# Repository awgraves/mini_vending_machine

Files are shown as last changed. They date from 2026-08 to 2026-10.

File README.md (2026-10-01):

# mini_vending_machine
A desktop-sized machine that dispenses snacks via a 2-axis motorized gantry

## Local Dev Setup
Assumes a Linux host

### Requirements
[Devenv.sh](https://devenv.sh/getting-started/) is the only direct dependency.
It is a convenient way to create deterministic, reproducible dev environments with automatic tooling setup!
Devenv uses the nix package manager and will automatically download and install isolated tooling dependencies that will not pollute your host system.
See the 'steps' section below.

#### Permissions
Assuming you are on linux:
For dfu-util (openocd flashing) & picocom (serial monitor) access, there are 2 options:
1. Use sudo for `sudo make flash` and `sudo make monitor`
2a. Add udev rule:
```
  SUBSYSTEM=="tty", ATTR{idVendor}=="0483", MODE="0666", TAG+="uaccess"
```
2b. Add 'dialout' group for your user for picocom (requires complete logout to take effect).

### Steps
1. Before cloning the repo, first create a workspace dir ie `mkdir workspace`
2. `cd` into the newly created dir and git clone this repo there.
3. Ensure nix package manager and devenv is installed, then exec `devenv shell` to enter the development shell.
All software dependencies will be automatically installed to a sandboxed environment!
The first time setup will take some time, but subsequent dev shell loads will be super quick.
You can leave the shell with `exit`.

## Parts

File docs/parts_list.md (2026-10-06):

# Parts List

## Frame
- [400mm vslot 2020](https://www.amazon.com/dp/B099MRRKJ2) x 6 pieces
- [400mm vslot 2040](https://www.amazon.com/dp/B0BZ57L6CB) x 4 pieces
- [450mm vslot 2020](https://www.amazon.com/dp/B099MJN26Z) x 4 pieces
- [L corner brackets](https://www.amazon.com/dp/B0F31DXF4F) x 12 pieces

## 3D Printer Filaments
- [Black PETG](https://www.amazon.com/dp/B07PGYHYV8)
- [White PLA+](https://www.amazon.com/dp/B09Q5YJ5HZ)

## PCB Boards, Wires, Connectors
- [9x15cm double sided prototype circuit boards](https://www.amazon.com/dp/B08WJBS4HK) x 2 pieces
- [22 awg stranded wire](https://www.amazon.com/dp/B07G2JWYDW)
- [22 awg solid core wire](https://www.amazon.com/dp/B07TX6BX47)
- TODO, jst connector info

## Gantry
- [STM32 blackpill F411CE](https://www.amazon.com/dp/B0DLNDY4V7) x 1 piece
- [nema 17 pancake stepper motors](https://www.amazon.com/dp/B088BNVTBF) x 2 pieces
- [limit switches](https://www.amazon.com/dp/B09K7K3486) x 2 pieces
- 100nF ceramic capacitors for switch debouncing x 2 pieces
- 10k ohm pullup resistors for switches x 2 pieces
- [TMC2209 stepper motor drivers](https://www.amazon.com/dp/B08WZFK9KT) x 2 pieces
- [100uF 50V electrolytic capacitors](https://www.amazon.com/dp/B0FVG9S7N6) for motor driver decoupling x 2 pieces

### X Axis
- [350mm vslot 2040](https://www.amazon.com/dp/B08X4NFVT6) (400mm cut down to 350mm)
- [350mm MGN9 linear rail](https://www.amazon.com/dp/B094CYT6JW) x 1 piece
- [GT2 6mm wide timing belt kit](https://www.amazon.com/dp/B07TGGVSTP)  x 1 piece
- M3 x 8mm screws & T nuts x 16 pieces for rail attachment
- [Nema 17 mount plate](https://www.amazon.com/dp/B07V3Q4WFL) x 1 piece

### Y Axis
- [300mm T8 leadscrew](https://www.amazon.com/dp/B0981YZ7DN) x 1 piece
- [Backlash-resistant T8 leadscrew nut](https://www.amazon.com/dp/B0B2P9KBH8) x 1 piece
- M5 x 16mm & hex nuts x 2 pieces to connect leadscrew nut to carriage wedge
- [5mm to 8mm flexible coupling for Nema 17](https://www.amazon.com/dp/B079J22KX1) x 1 piece
- Bearing (came with [this kit](https://www.amazon.com/dp/B08T9PL29W)) x 1 piece
- [400mm MGN9 linear rail](https://www.amazon.com/dp/B094CXXPLG)
- M3 x 8mm screws & T nuts x 18 pieces for rail attachment

## Dispenser
- M3 x 6mm screws & hex nuts x 16 pieces for inter-cubby attachments
- M3 x 8mm screws & hex nuts x 12 pieces for drawer slide verticle attachments
- [8inch drawer slides](https://www.amazon.com/dp/B0D62TB3V7) x 6 pieces
- M5 x 12mm screws & hex nuts x 12 pieces for drawer slide to cubby attachment
- M5 x 8mm screws & hex nuts x 10 pieces for cubby legs attachments

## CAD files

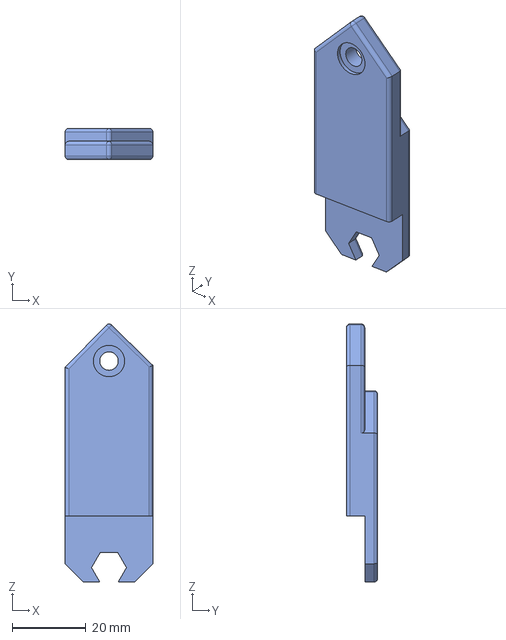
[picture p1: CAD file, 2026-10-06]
docs/3d/cubby_legs_slide_attach.step
23.8 x 8.50 x 69.9 mm

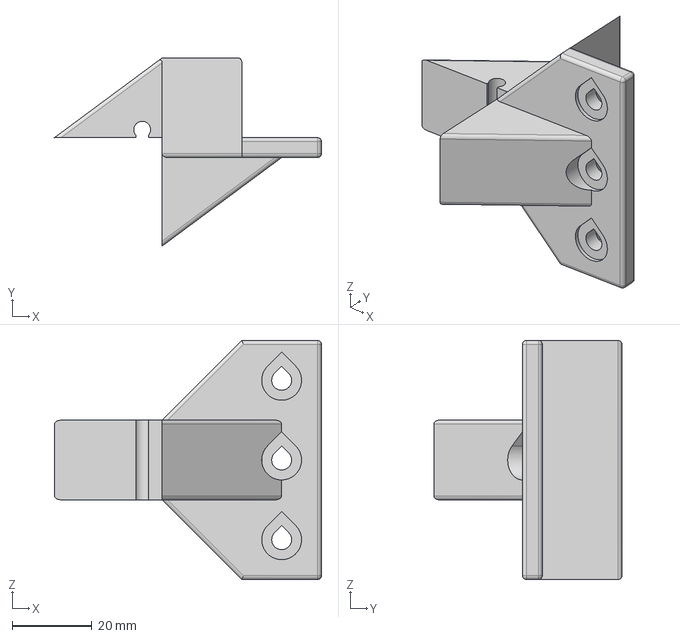
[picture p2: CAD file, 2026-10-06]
docs/3d/cubby_vslot_attachment.step
67.0 x 47.2 x 60.0 mm

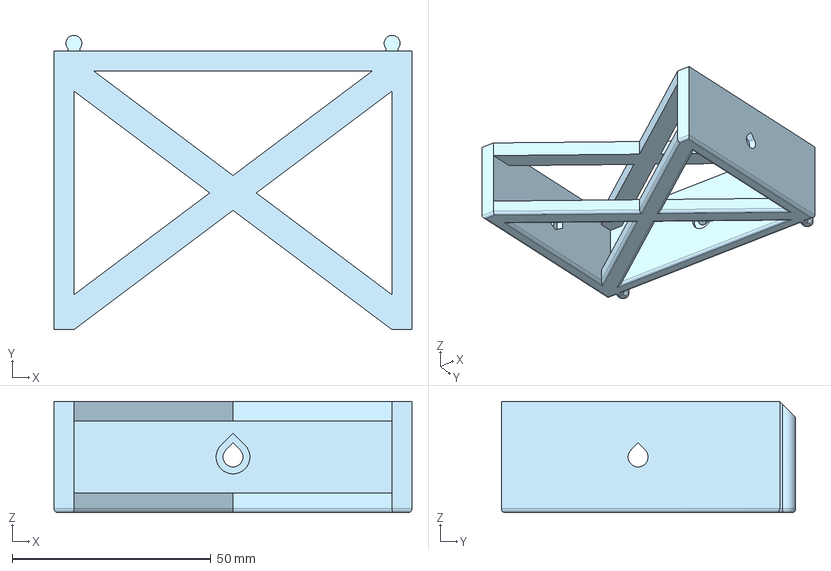
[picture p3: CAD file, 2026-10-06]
docs/3d/cubby_legs.step
90.0 x 74.0 x 28.0 mm

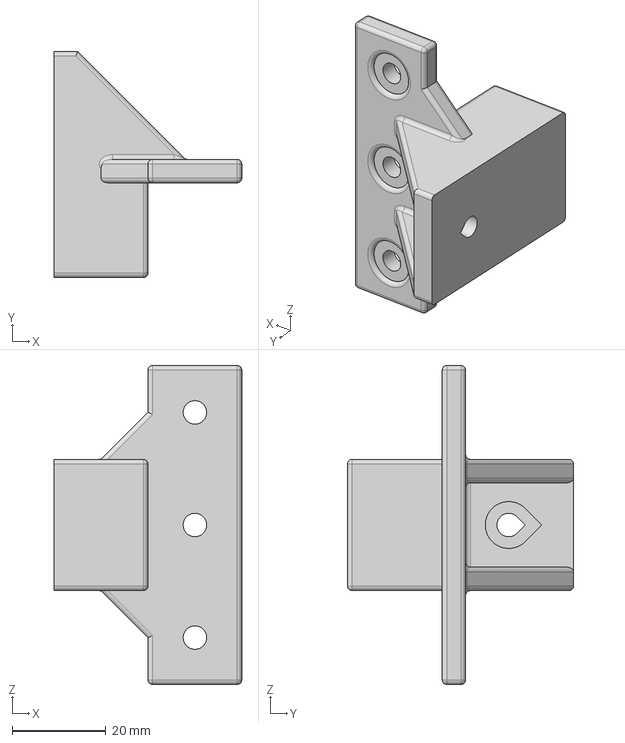
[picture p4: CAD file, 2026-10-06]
docs/3d/cubby_legs_spacer.step
40.0 x 48.2 x 68.0 mm

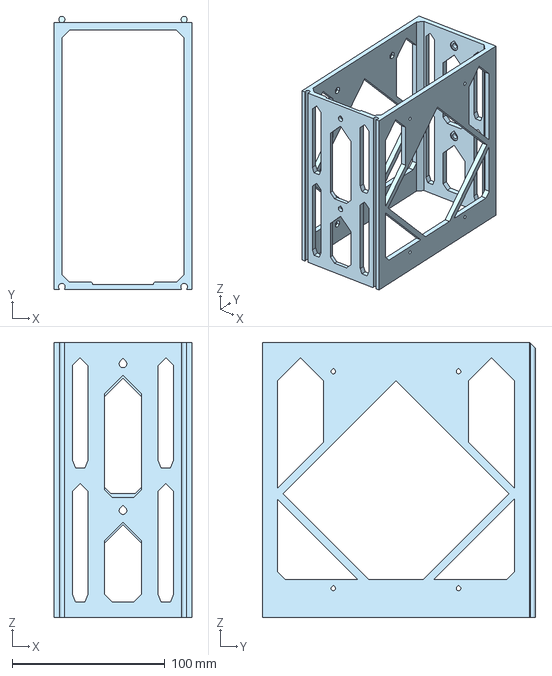
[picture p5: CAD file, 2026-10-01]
docs/3d/cubby_unit.step
90.0 x 179.0 x 180.0 mm

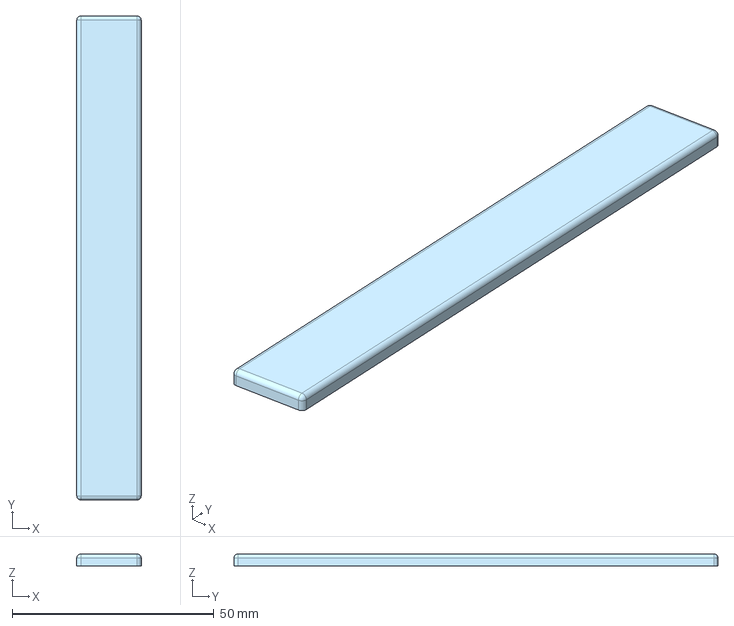
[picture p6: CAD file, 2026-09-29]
docs/3d/120mm_spacer.step
16.0 x 120.0 x 3.00 mm

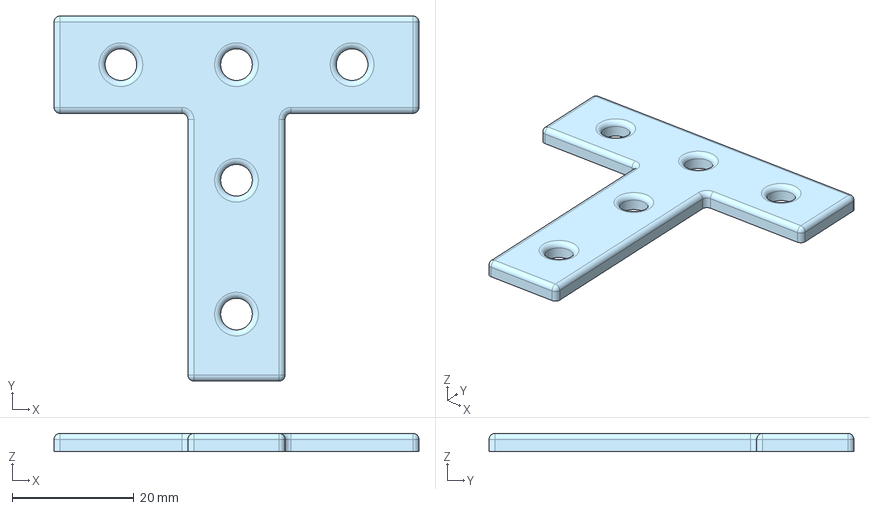
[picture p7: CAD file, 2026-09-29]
docs/3d/t_bracket.step
60.0 x 60.0 x 3.00 mm

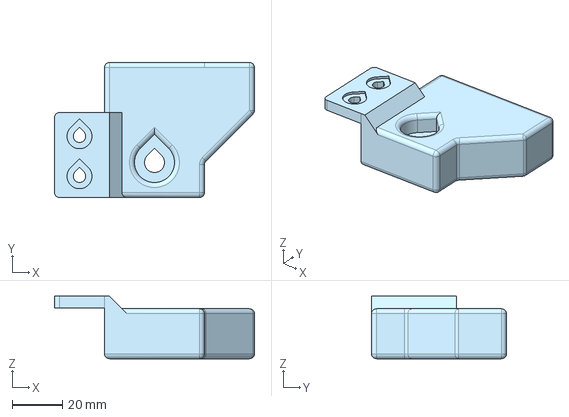
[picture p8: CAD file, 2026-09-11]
docs/3d/y_axis_bearing_bracket.step
80.0 x 54.0 x 25.0 mm

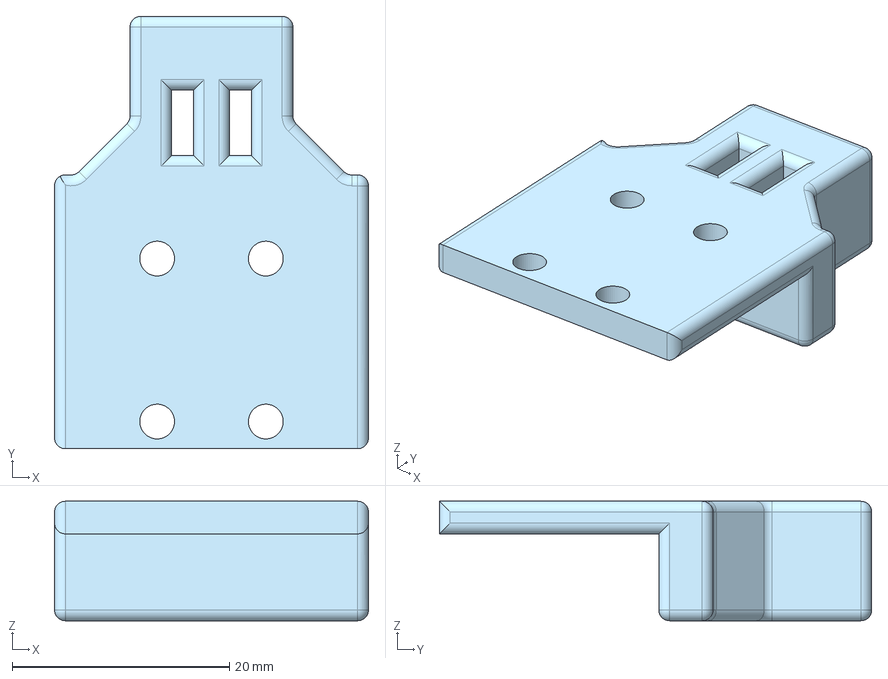
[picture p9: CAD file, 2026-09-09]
docs/3d/x_axis_timing_belt_carriage.step
28.9 x 39.8 x 11.0 mm

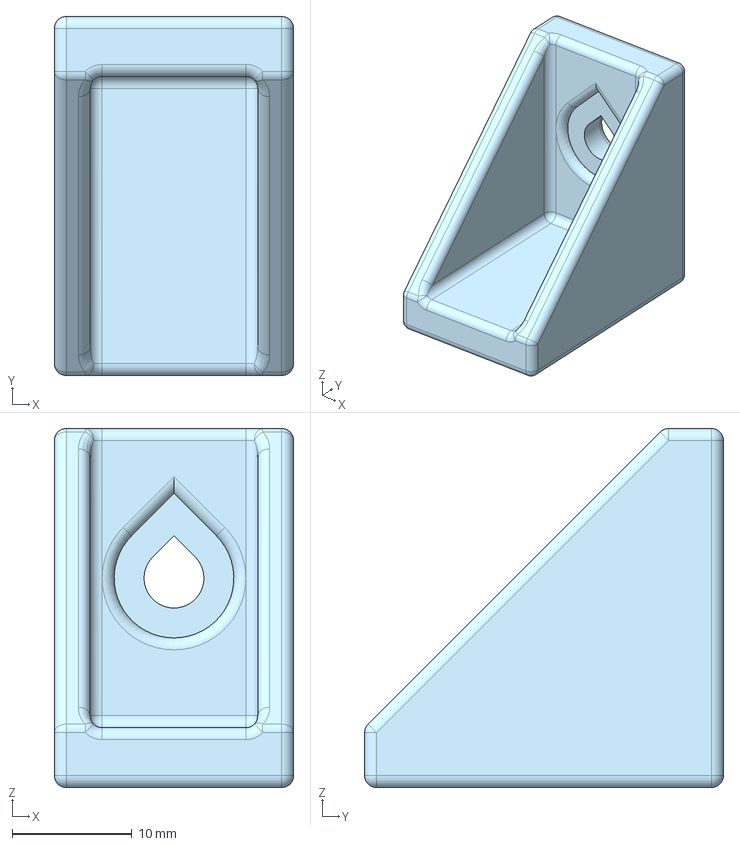
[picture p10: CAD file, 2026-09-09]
docs/3d/y_axis_rail_spacer.step
20.0 x 30.0 x 30.0 mm

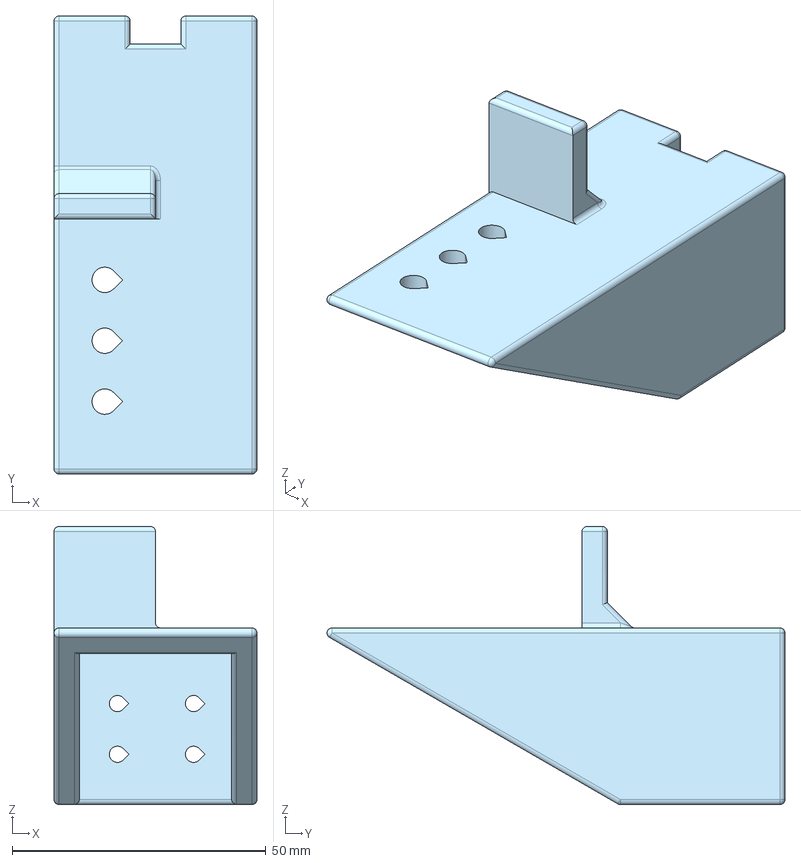
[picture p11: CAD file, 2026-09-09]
docs/3d/y_axis_rail_carriage.step
40.0 x 90.3 x 54.8 mm

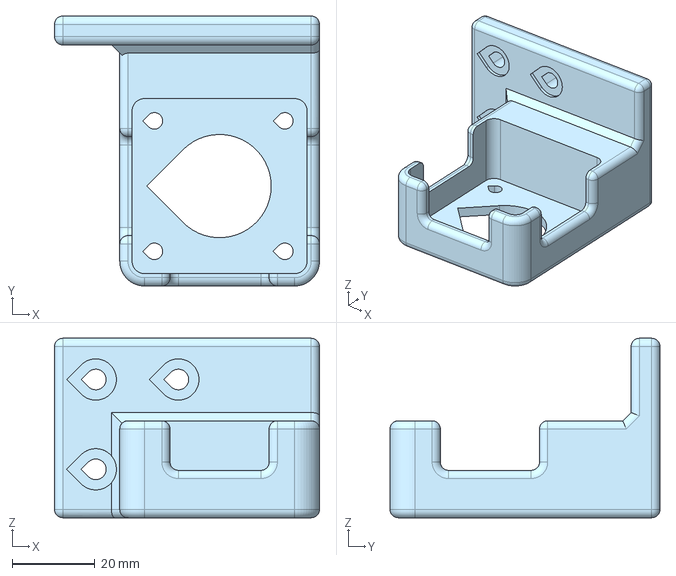
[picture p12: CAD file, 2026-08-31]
docs/3d/y_axis_stepper_mount.step
64.2 x 65.4 x 43.5 mm

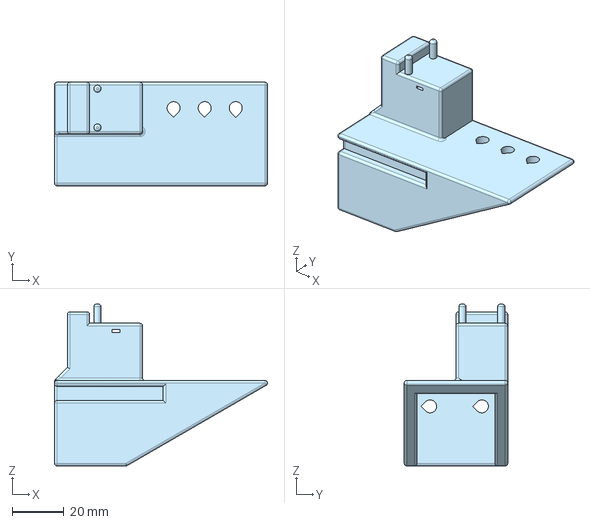
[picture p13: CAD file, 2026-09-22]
docs/3d/y_axis_leadscrew_carriage.step
82.3 x 40.0 x 62.5 mm

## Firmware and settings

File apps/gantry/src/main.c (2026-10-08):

#include "gantry.h"
#include <stdio.h>
#include <zephyr/kernel.h>

#define SLEEP_TIME_MS 20

void loop_message(const char *msg) {
  while (1) {
    printf("%s\n", msg);
    k_msleep(SLEEP_TIME_MS);
  }
}

uint8_t cmd_idx;
K_SEM_DEFINE(blocking_cmd_sem, 0, 1);

void gantry_cb(const struct gantry_event *ev) {
  if (ev->type != GANTRY_MOVE_COMPLETED) {
    printf("Something went wrong. Err code %d\n",
           (enum gantry_err_type)ev->data);
  }
  k_sem_give(&blocking_cmd_sem);
}

int main(void) {
  gantry_init();

  k_msleep(1000);

  gantry_register_event_cb(gantry_cb);

  int ret;
  struct gantry_cmd cmd;
  enum gantry_pos positions[7] = {POS_A, POS_B, POS_C,   POS_D,
                                  POS_E, POS_F, POS_HOME};
  for (cmd_idx = 0; cmd_idx < (sizeof(positions) / sizeof(enum gantry_pos));
       cmd_idx++) {
    cmd.type = GANTRY_MOVE;
    cmd.target_pos = (enum gantry_pos)positions[cmd_idx];

    ret = gantry_cmd_send(&cmd);
    if (ret < 0) {
      printf("gantry cmd failed!\n");
      break;
    }
    printf("Trying position %d...\n", positions[cmd_idx]);
    ret = k_sem_take(&blocking_cmd_sem, K_SECONDS(20));
    if (ret != 0) {
      printf("Timeout!\n");
    }

    k_msleep(1000);
  }

  while (1) {
    k_msleep(SLEEP_TIME_MS);
  }

  return 0;
};

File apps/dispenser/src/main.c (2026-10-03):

#include <zephyr/drivers/can.h>
#include <zephyr/drivers/gpio.h>
#include <zephyr/drivers/led.h>
#include <zephyr/kernel.h>

#define DELAY_MS 1000

const struct led_dt_spec led = LED_DT_SPEC_GET(DT_ALIAS(led));
const struct gpio_dt_spec btn = GPIO_DT_SPEC_GET(DT_ALIAS(sw), gpios);
const struct device *can_dev = DEVICE_DT_GET(DT_ALIAS(canbus));

static K_SEM_DEFINE(tx_done, 0, 1);

static void tx_cb(const struct device *dev, int error, void *user_data) {
  printk("tx callback, error=%d\n", error);
  k_sem_give(&tx_done);
}

CAN_MSGQ_DEFINE(rx_q, 4);

const struct can_filter filter = {
    .id = 0x123, .mask = CAN_STD_ID_MASK, .flags = 0};

int main(void) {

  k_msleep(5000);
  printk("Starting up...\n");

  if (!led_is_ready_dt(&led) || !gpio_is_ready_dt(&btn) ||
      !device_is_ready(can_dev)) {
    printk("A device failed to init\n");
    return 0;
  }

  gpio_pin_configure_dt(&btn, (GPIO_ACTIVE_LOW | GPIO_PULL_UP | GPIO_INPUT));

  int ret;

  ret = can_set_bitrate(can_dev, 250000); // 250kb/s
  if (ret) {
    printk("set_bitrate failed [%d]\n", ret);
    return 0;
  }
  can_set_mode(can_dev, CAN_MODE_LOOPBACK); // needed if only module on bus
  ret = can_start(can_dev);
  if (ret) {
    printk("can_start failed [%d]\n", ret);
    return 0;
  }

  printk("CAN should be started\n");

  can_add_rx_filter_msgq(can_dev, &rx_q, &filter);

  struct can_frame tx = {
      .flags = 0, /* 0 = standard 11-bit ID */
      .id = 0x123,
      .dlc = 8,
      .data = {1, 2, 3, 4, 5, 6, 7, 8},
  };
  struct can_frame rx;

  printk("made it, should start looping\n");

  while (1) {
    if (gpio_pin_get_dt(&btn)) {
      led_on_dt(&led);
    } else {
      led_off_dt(&led);
    }
    ret = can_send(can_dev, &tx, K_MSEC(100), tx_cb, NULL);
    printk("can_send queued: %d\n", ret);

    if (k_sem_take(&tx_done, K_MSEC(500)) != 0) {
      enum can_state state;
      struct can_bus_err_cnt cnt;
      can_get_state(can_dev, &state, &cnt);
      printk("TX never completed. state=%d tx_err=%u rx_err=%u\n", state,
             cnt.tx_err_cnt, cnt.rx_err_cnt);
    }

    if (k_msgq_get(&rx_q, &rx, K_MSEC(200)) == 0) {
      printk("RECEIVED! rx id=0x%x dlc=%u data=", rx.id, rx.dlc);
      for (int i = 0; i < rx.dlc; i++) {
        printk("%u ", rx.data[i]);
      }
      printk("\n");
    }
    k_msleep(DELAY_MS);
  }
  return 0;
}

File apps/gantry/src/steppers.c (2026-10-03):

#include "steppers.h"
#include <stdint.h>
#include <zephyr/drivers/gpio.h>
#include <zephyr/drivers/stepper/stepper.h>
#include <zephyr/drivers/stepper/stepper_ctrl.h>
#include <zephyr/drivers/uart.h>
#include <zephyr/kernel.h>

// #define INCLUDE_STEPPER_UART_READS
#define DIR_OF_LIMIT_SWITCH STEPPER_CTRL_DIRECTION_NEGATIVE

struct stepper {
  const char name;
  const struct device *driver;
  const struct device *ctrl;
  const struct gpio_dt_spec limit_sw;
  struct k_sem *event_sem;
};

static struct stepper steppers[STEPPER_AXIS_COUNT] = {
    [STEPPER_X_AXIS] =
        {
            .name = 'X',
            .driver = DEVICE_DT_GET(DT_ALIAS(stepper_driver_x)),
            .ctrl = DEVICE_DT_GET(DT_ALIAS(stepper_ctrl_x)),
            .limit_sw = GPIO_DT_SPEC_GET(DT_ALIAS(stepper_limit_x), gpios),
            .event_sem = NULL,
        },
    [STEPPER_Y_AXIS] = {
        .name = 'Y',
        .driver = DEVICE_DT_GET(DT_ALIAS(stepper_driver_y)),
        .ctrl = DEVICE_DT_GET(DT_ALIAS(stepper_ctrl_y)),
        .limit_sw = GPIO_DT_SPEC_GET(DT_ALIAS(stepper_limit_y), gpios),
        .event_sem = NULL,
    }};

static const struct device *const uart_dev =
    DEVICE_DT_GET(DT_ALIAS(steppers_uart));

/*
  Helpers
*/

// --- Steppers UART ---
// per
// https://www.analog.com/media/en/technical-documentation/data-sheets/tmc2209_datasheet_rev1.09.pdf
#define TMC2209_SYNC 0x05

// pg. 23
#define GCONF_REG_ADDR 0x00
#define GCONF_PDN_DISABLE (0x1 << 6)
#define GCONF_MSTEP_REG_SELECT_UART (0x1 << 7) // rather than ms1/ms2 pins
#define GCONF_VALS (GCONF_PDN_DISABLE | GCONF_MSTEP_REG_SELECT_UART)

#define IFCNT 0x02

#define CHOPCONF_REG_ADDR 0x6C
#define CHOPCONF_MRES(s) (((s) & 0xF) << 24)
#define MRES_8 0x5
// #define MRES_16 0x4

// taking these defaults from pg. 70
#define CHOPCONF_TOFF (0x5)
#define CHOPCONF_TBL (0x2 << 15)
#define CHOPCONF_HSTART (0x4 << 4)
#define CHOPCONF_HEND (0 << 7)
#define CHOPCONF_VALS                                                          \
  (CHOPCONF_TOFF | CHOPCONF_TBL | CHOPCONF_HSTART | CHOPCONF_HEND |            \
   CHOPCONF_MRES(MRES_8))

// pg. 28
#define IHOLD_IRUN_REG_ADDR 0x10
#define IHOLD_IRUN_IHOLD(v) ((v) & 0x1F)
#define IHOLD_IRUN_IRUN(v) (((v) & 0x1F) << 8)
#define IHOLD_IRUN_IHOLDDELAY(v) (((v) & 0xF) << 16)
// targeting max 1A, formula on pg. 53
#define IHOLD_IRUN_VALS                                                        \
  (IHOLD_IRUN_IHOLD(2) | IHOLD_IRUN_IRUN(16) | IHOLD_IRUN_IHOLDDELAY(4))

#define MIN_NS_INTERVAL 100000
#define NS_INTERVAL_PER_TICK (MIN_NS_INTERVAL / 100)
#define NS_INTERVAL_SLOWEST (MIN_NS_INTERVAL + (NS_INTERVAL_PER_TICK * 100))

#define TMC2209_BUS_ADDR 0x0 // using same for both steppers (sharing configs)

struct datagram {
  uint8_t sync;
  uint8_t node_addr; // 0 - 3
  uint8_t reg;       // highest bit is the read/or write, 7 remaining are addr
  uint8_t data[4];   // big endian
  uint8_t crc;
};

// per pg. 20 of tmc2209 datasheet
void add_crc(uint8_t *datagram, uint8_t len) {
  int i, j;
  uint8_t *crc = datagram + (len - 1); // CRC located in last byte of message
  uint8_t currentByte;
  *crc = 0;
  for (i = 0; i < (len - 1); i++) { // Execute for all bytes of a message
    currentByte = datagram[i];      // Retrieve a byte to be sent from Array
    for (j = 0; j < 8; j++) {
      if ((*crc >> 7) ^
          (currentByte & 0x01)) // update CRC based result of XOR operation
      {
        *crc = (*crc << 1) ^ 0x07;
      } else {
        *crc = (*crc << 1);
      }
      currentByte = currentByte >> 1;
    } // for CRC bit
  } // for message byte
}

static void build_write_datagram(struct datagram *dg, uint8_t dev_addr,
                                 uint8_t reg, uint32_t value) {
  dg->sync = TMC2209_SYNC;
  dg->node_addr = dev_addr;
  dg->reg = reg | 0x80;      // always write mode
  dg->data[0] = value >> 24; // swap to big endian
  dg->data[1] = value >> 16;
  dg->data[2] = value >> 8;
  dg->data[3] = value >> 0;
  add_crc((uint8_t *)dg, sizeof(struct datagram));
}

void uart_write(uint8_t reg, uint32_t value) {
  struct datagram dg;
  build_write_datagram(&dg, TMC2209_BUS_ADDR, reg, value);

  uint8_t *dg_bytes = (uint8_t *)&dg;
  for (int i = 0; i < sizeof(struct datagram); i++) {
    uart_poll_out(uart_dev, dg_bytes[i]);
  }
}

#ifdef INCLUDE_STEPPER_UART_READS
struct datagram_read {
  uint8_t sync;
  uint8_t node_addr;
  uint8_t reg;
  uint8_t crc;
};

static void build_read_datagram(struct datagram_read *dg, uint8_t dev_addr,
                                uint8_t reg) {
  dg->sync = TMC2209_SYNC;
  dg->node_addr = dev_addr;
  dg->reg = reg;
  add_crc((uint8_t *)dg, sizeof(struct datagram_read));
}
// used just for debugging with logic analyzer
void read(uint8_t reg) {
  struct datagram_read dgr;
  uint8_t *dgr_bytes = (uint8_t *)&dgr;

  build_read_datagram(&dgr, TMC2209_BUS_ADDR, reg);
  for (int i = 0; i < sizeof(struct datagram_read); i++) {
    uart_poll_out(uart_dev, dgr_bytes[i]);
  }
  k_msleep(1);
}
#endif

// ---- Limit Switches -----
static struct gpio_callback limit_sw_cb_data;

void limit_switch_isr(const struct device *dev, struct gpio_callback *cb,
                      uint32_t pins) {

  for (int i = 0; i < STEPPER_AXIS_COUNT; i++) {
    struct stepper *s = &steppers[i];
    if (BIT(s->limit_sw.pin) & pins) {
      stepper_stop(s);
      stepper_ctrl_set_reference_position(s->ctrl, 0);
      if (s->event_sem) {
        k_sem_give(s->event_sem);
        printk("limit switch isr hit for %c\n", s->name);
      }
    }
  }
}

// ---- Motor Events ----

static void stepper_event_callback(const struct device *dev,
                                   const enum stepper_ctrl_event event,
                                   void *user_data) {

  switch (event) {
  case STEPPER_CTRL_EVENT_STEPS_COMPLETED:
    struct stepper *s = (struct stepper *)user_data;
    if (s->event_sem) {
      k_sem_give(s->event_sem);
    }
    break;
  default:
    break;
  }
}

// ---- Misc ----
static inline uint64_t get_microstep_interval(uint8_t speed) {
  return NS_INTERVAL_SLOWEST - (NS_INTERVAL_PER_TICK * speed);
};

void log_err(const struct stepper *stepper, const char *msg) {
  printk("Error - Stepper %c: %s\n", stepper->name, msg);
}

static inline bool is_valid_speed(uint8_t speed) {
  return (speed > 0 && speed <= 100);
}

/*
  Public API
*/
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

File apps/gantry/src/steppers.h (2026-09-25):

#pragma once
#include <zephyr/drivers/stepper/stepper_ctrl.h>

#define STEPPER_STEPS_PER_REV 200
#define STEPPER_MICRO_STEPS_SETTING 8
#define STEPPER_MICRO_STEPS_PER_REV                                            \
  (STEPPER_STEPS_PER_REV * STEPPER_MICRO_STEPS_SETTING)

struct stepper;

#define STEPPER_AXIS_COUNT 2
enum stepper_axis { STEPPER_X_AXIS = 0, STEPPER_Y_AXIS };

struct stepper_run_conf {
  uint8_t speed; // min 1, max 100
  enum stepper_ctrl_direction dir;
};

int steppers_init(void);
struct stepper *stepper_get(enum stepper_axis axis);

void stepper_set_event_sem(struct stepper *s, struct k_sem *sem);

int stepper_stop(struct stepper *s);
// TODO: remove stepper_run once positioning logic exists
int stepper_run(struct stepper *s, const struct stepper_run_conf *conf);

/* Limit related funcs */
bool stepper_get_is_at_limit(struct stepper *s);
int stepper_read_curr_step_count(struct stepper *s, int32_t *pos);
int stepper_run_until_limit_hit(struct stepper *s, uint8_t speed);

int stepper_set_speed(struct stepper *s, uint8_t speed);
int stepper_move_steps(struct stepper *s, int32_t steps);

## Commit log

2026-08-07 reference the user button
2026-08-08 switch to zephyr 4.4.2, play with usb serial interface
2026-08-12 practice with button toggling light + serial message
2026-08-12 create gantry app with initial single axis ADC reading
2026-08-13 add second joystick axis ADC read
2026-08-14 add pwm leds to indicate joystick adc readings
2026-08-17 created dedicated joystick module / driver
2026-08-17 switch to named io-channels for joystick init
2026-08-17 refactor to simpler /drivers module
2026-08-18 quick, basic 2 direction stepper motor
2026-08-20 simplify current code
2026-08-20 add separate steppers.c, refactor joystick logic to handle normalization
2026-08-20 switch joystick to use pb0 and pb1
2026-08-24 add UART configuration for stepper motor
2026-08-25 working second motor
2026-08-25 simplify steppers interface
2026-08-27 first pass 3d print carriage attach and leadscrew block
    [leadscrew_block.step, test_carriage_mount.step]
2026-08-27 iterate leadscrew block and test carriage
    [leadscrew_block.step, test_carriage_mount.step]
2026-08-31 iterate y axis brackets again, swap motor to top with bearing at bottom
    [y_axis_bearing_bracket.step, y_axis_stepper_mount.step]
2026-09-01 model x axis leadscrew block with side mount motor
    [leadscrew_block.step, x_axis_leadscrew_block.step]
2026-09-02 invert y axis stepper dir
2026-09-09 more y axis 3d iterations
    [test_carriage_mount.step, x_axis_leadscrew_block.step, y_axis_bearing_bracket.step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]
2026-09-09 increase stepper max speed
2026-09-09 model x axis belt carriage
    [x_axis_timing_belt_carriage.step]
2026-09-11 increase y axis bearing bracket size to contact limit switch
    [y_axis_bearing_bracket.step]
2026-09-16 naive limit switches ISRs
2026-09-18 add stepper_run_until_limit_hit functionality with registered cbs
2026-09-19 reorg steppers code and introduce gantry abstraction layer
2026-09-22 switch to devenv for tooling setup
2026-09-22 add ziptie slot for x axis stepper
    [y_axis_leadscrew_carriage.step]
2026-09-24 add gantry calibration logic
2026-09-25 basic gantry positioning, one axis at a time
2026-09-27 switch gantry to cmd queue async api
2026-09-27 parallel axis moves when not homing, different speeds per axis
2026-09-27 automatic homing on first move command
2026-09-29 t bracket and 120mm spacer
    [120mm_spacer.step, t_bracket.step]
2026-10-01 cubby unit
    [cubby_unit.step]
2026-10-03 gantry moving to 0 bugfix, adjust y axis speed, add print messages
    [gantry.c, main.c, steppers.c]
2026-10-06 cubby legs + leg spacers
    [cubby_legs.step, cubby_legs_spacer.step]
2026-10-06 cubby legs and vslot attachments
    [cubby_legs_slide_attach.step, cubby_vslot_attachment.step]
2026-10-07 begin wiring schematic
    [gantry_node.kicad_sch, mini_vending_machine.kicad_pcb, mini_vending_machine.kicad_sch]
2026-10-08 tweak y axis position heights and speed
2026-10-10 add gantry spi/can bus
2026-10-15 improve stepper limit switch debounce
2026-10-16 schematics: gantry, power, can bus
2026-10-16 switch gantry API to blocking calls, simplify logic
2026-10-16 gantry abort functionality, switch to events from semaphores
2026-10-27 redesign y axis carriages, add parts and printer setting notes
2026-10-27 dispenser test IR beam switch
2026-10-27 first POC dispenser motor + IR sensor
2026-11-02 shave 3.5mm off brackets bordering vslot frame sides
2026-11-02 remove joystick driver code
2026-11-02 gantry test code to cycle through positions and home return sequences
2026-11-03 dispenser motor output via shift register signal
2026-11-09 POC all 6 motors and beams
2026-11-11 exterior panel and handle brackets
2026-11-12 remove left gussets from y axis rail spacers
2026-11-13 dispenser node electrical schematics
2026-11-13 remove redundant stepper interrupt config dt
